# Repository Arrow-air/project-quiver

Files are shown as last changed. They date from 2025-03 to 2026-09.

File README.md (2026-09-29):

# Project Quiver

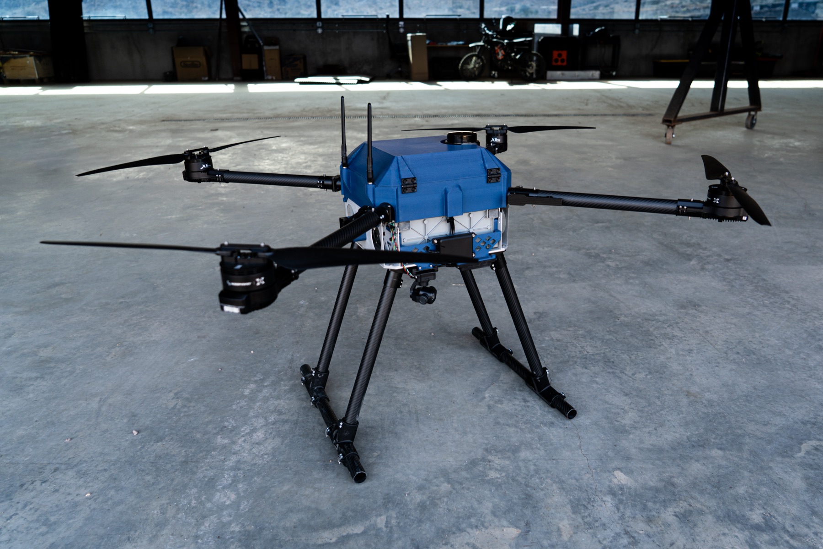
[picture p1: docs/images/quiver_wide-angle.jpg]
Project Quiver PT3


**An open-source, modular quadcopter platform for developers and operators.**

Project Quiver is a 25 kg MTOW drone with 5-8 kg payload capacity, three hot-swappable attachment interfaces, and a distributed electronics architecture. Built for reliability, field serviceability, and customization.

Developed by [Arrow Air](https://arrowair.com) and released under the CERN Open Hardware Licence.

## Key Features

- **Modular payload system** — Three quick-release interfaces (bottom, left, right) for mission equipment
- **Dual GNSS with RTK** — Centimeter-level positioning with backup redundancy
- **Distributed PCB architecture** — Four custom boards that can be individually serviced
- **25-31 min hover endurance** — Tattu 14S 30Ah smart battery with Hobbywing X6 Plus propulsion
- **ArduPilot firmware** — Standard QGroundControl/Mission Planner compatibility
- **Weatherproof design** — Sealed cockpit with rain canopies and drip-proof geometry

## Documentation

📖 **[Full Documentation](https://arrowair.com/quiver/)** — Platform overview, capabilities, and roadmap

The `docs/` folder is hosted on the [Arrow website](https://arrowair.com/quiver/).

| Resource | Description |
|---|---|
| [Assembly Guides](https://arrowair.com/quiver/category/manufacturing/) | Step-by-step build instructions |
| [Engineering Reports](https://arrowair.com/quiver/category/reference--engineering-reports/) | Technical details for each prototype |
| [Meeting Notes](https://github.com/Arrow-air/project-quiver/wiki) | Engineering call notes |

## Repository Structure

```
project-quiver/
├── docs/                    # Documentation (hosted at arrowair.com/quiver)
├── src/
│   ├── quiver/              # CAD assembly — build123d Python package
│   ├── pcb/                 # KiCad PCB designs (4 custom boards)
│   ├── printing/            # 3D print profiles and settings
│   └── manufacturing/       # DXFs and cut sheets for CNC/laser
├── flight-test/             # Historical flight test logs
└── task-grant-bounty/       # Bounty and grant task specifications
```

### CAD Assembly

The CAD source is a [build123d](https://github.com/gumyr/build123d) Python package that composes STEP files into the full drone assembly. This enables programmatic CAD generation and version-controlled mechanical design. See [`src/quiver/`](src/quiver/) for details.

## Getting Started

**Want to build one?** Start with the [Assembly Guides](https://arrowair.com/quiver/category/manufacturing/).

**Want to develop attachments?** Check out:
- [Possible Attachment List](task-grant-bounty/equipment/attachment/0001-possible_attachment_list/information-note.md)
- [Priority Attachment Requirements](task-grant-bounty/equipment/attachment/0002-detailed_attachment_requirement_for_bounty/information-note.md)

**Want a dev-kit?** Dev-kit drones are available for loan to developers with promising projects. Join the [Arrow Discord](https://discord.gg/arrow) to learn more.

## Contributing

We welcome contributions across:
- **Attachments** — Design new payloads for the modular interfaces
- **Electronics** — PCB improvements and new sensor integrations  
- **Mechanical** — Structural design and manufacturing optimization
- **Software** — ArduPilot configs, companion computer features, tooling
- **Documentation** — Guides, tutorials, and translations

See [CONTRIBUTING.md](CONTRIBUTING.md) for guidelines.

## Community

- **Discord** — [discord.gg/arrow](https://discord.gg/arrow)
- **DAO Forum** — [dao.arrowair.com](https://dao.arrowair.com)
- **Flight Tracking** — [project-flight-tracking.vercel.app](https://project-flight-tracking.vercel.app/)

## License

[CERN Open Hardware Licence Version 2 - Strongly Reciprocal (CERN-OHL-S)](LICENSE)

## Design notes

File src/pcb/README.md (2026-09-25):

# PCB Designs

KiCad projects for the Quiver's distributed PCB architecture.

## Board projects

| Directory | BOM | KiCad project | Description |
|---|---|---|---|
| `battery_pcb/` | 3311 | `Front_PCB` (V1.3) | Battery PCB — power switching and protection |
| `main_pcb/` | 3321 | `Quiver_PT3_Main_PCB-rounded` (V1.2) | Main PCB — power and data distribution hub. V1.2 is the board on the Dev-Kit aircraft. |
| `fc_pcb/` | 3331 | `Quiver_PT3_FC_PCB` | Flight Controller PCB — Pix32 V6 adapter board |
| `attach_pcb/` | 3341 | `QuiverAttachPCB` (V1.4) | Attachment Interface PCB (x3) |

Production gerbers live in each project's `production/` folder. Design
history, update notes, and superseded board revisions remain with the
bounty tasks under
[`task-grant-bounty/pt3/electronics/`](../../task-grant-bounty/pt3/electronics/).

## STEP export workflow

Each KiCad project can export a 3D STEP model of the assembled board.
These STEP files go into the CAD assembly tree:

```
pcb/<board>/  ──(KiCad 3D export)──►  ../quiver/equipment/pcb/steps/{BOM}_{name}.step
```

For example, exporting `battery_pcb` produces `3311_battery_pcb.step`, which
should be placed in `../quiver/equipment/pcb/steps/`.

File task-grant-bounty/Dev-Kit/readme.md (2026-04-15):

This folder contains the various information notes prepared for the Dev-Kit build of Project Quiver

- Main PCB Update
- Front PCB Update
- Obstacle Avoidance
- Software in the Loop (SITL) Evaluation
- PCB Vibration Mount
- Comprehensive Main Enclosure Modification
- Sensor Mount Re-modeling
- Structure Weight Reduction
- Improvement of Dust and Water Resistance
- Ethernet Setup Guide

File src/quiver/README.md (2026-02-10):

# Quiver CAD Assembly

Parametric CAD for the Arrow Quiver multi-purpose quadcopter platform,
built with [build123d](https://github.com/gumyr/build123d).

## Folder structure

The project follows the Quiver Bill of Materials (BOM) hierarchy. Top-level
folders map to BOM categories (1000–5000), and subfolders map to subcategories
(XX00). Folder names are descriptive (no numeric prefixes); BOM numbers appear
in STEP file names and module docstrings.

| BOM  | Category / Subcategory | Folder path |
|---|---|---|
| 1000 | Airframe Structure | `airframe_structure/` |
| 1100 | Plates | `airframe_structure/plates/` |
| 1200 | Beams | `airframe_structure/beams/` |
| 1300 | Landing Gear | `airframe_structure/landing_gear/` |
| 1400 | Motor Arm | `airframe_structure/motor_arm/` |
| 2000 | Supporting Structure | `supporting_structure/` |
| 2100 | Attachment Interface | `supporting_structure/attachment_interface/` |
| 2200 | Battery Slider | `supporting_structure/battery_slider/` |
| 2300 | Equipment Mount | `supporting_structure/equipment_mount/` |
| 2400 | Cockpit Enclosure | `supporting_structure/cockpit_enclosure/` |
| 3000 | Equipment | `equipment/` |
| 3100 | Propulsion System | `equipment/propulsion/` |
| 3200 | Peripheral | `equipment/peripheral/` |
| 3300 | PCB | `equipment/pcb/` |
| 3400 | Battery | `equipment/battery/` |
| 4000 | Harness | `harness/` |

Two additional folders live outside the BOM hierarchy:

- **`attachments/designs/`** — Community payload attachment designs
- **`variants/`** — Major structural variant builds

## STEP file naming

STEP files use BOM component numbers as prefixes for traceability:

```
{XXXX}_{descriptive_name}.step
```

Examples:
- `1111_upper_plate.step`
- `1211_cw_long.step`
- `3111_motor.step`

## Custom vs vendor parts

Each subcategory has a `steps/` directory for STEP files:

- **`steps/`** — Custom-designed parts (exported from Fusion 360 or built
  parametrically)
- **`steps/vendor/`** — Supplier-provided STEP models for off-the-shelf
  components (motors, tubes, hinges, etc.)

## Running the assembly

Export the full drone as a STEP file:

```bash
python -m quiver.assembly
```

View in the ocp-vscode 3D viewer:

```bash
python -m quiver.assembly --show
```

Export to a custom path:

```bash
python -m quiver.assembly -o path/to/output.step
```

## Assembly hierarchy

The top-level `assembly.py` composes three BOM categories. Each category
composes its subcategories, and each subcategory loads STEP files from its
`steps/` directory.

```
quiver.assembly
├── airframe_structure.assembly    (1000)
│   ├── plates.assembly            (1100)
│   ├── beams.assembly             (1200)
│   ├── landing_gear.assembly      (1300)
│   └── motor_arm.assembly         (1400)
├── supporting_structure.assembly  (2000)
│   ├── attachment_interface.assembly (2100)
│   ├── battery_slider.assembly    (2200)
│   ├── equipment_mount.assembly   (2300)
│   └── cockpit_enclosure.assembly (2400)
└── equipment.assembly             (3000)
    ├── propulsion.assembly        (3100)
    ├── peripheral.assembly        (3200)
    ├── pcb.assembly               (3300)
    └── battery.assembly           (3400)
```

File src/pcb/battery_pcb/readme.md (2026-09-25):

PCB files are up to date as of 01/05/26 (Front PCB V1.3, the board on the Dev-Kit aircraft). V1.2 gerbers remain in `production/` for reference.

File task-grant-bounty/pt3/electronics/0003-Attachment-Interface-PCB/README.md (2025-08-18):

# Project Quiver Payload Attachment PCB

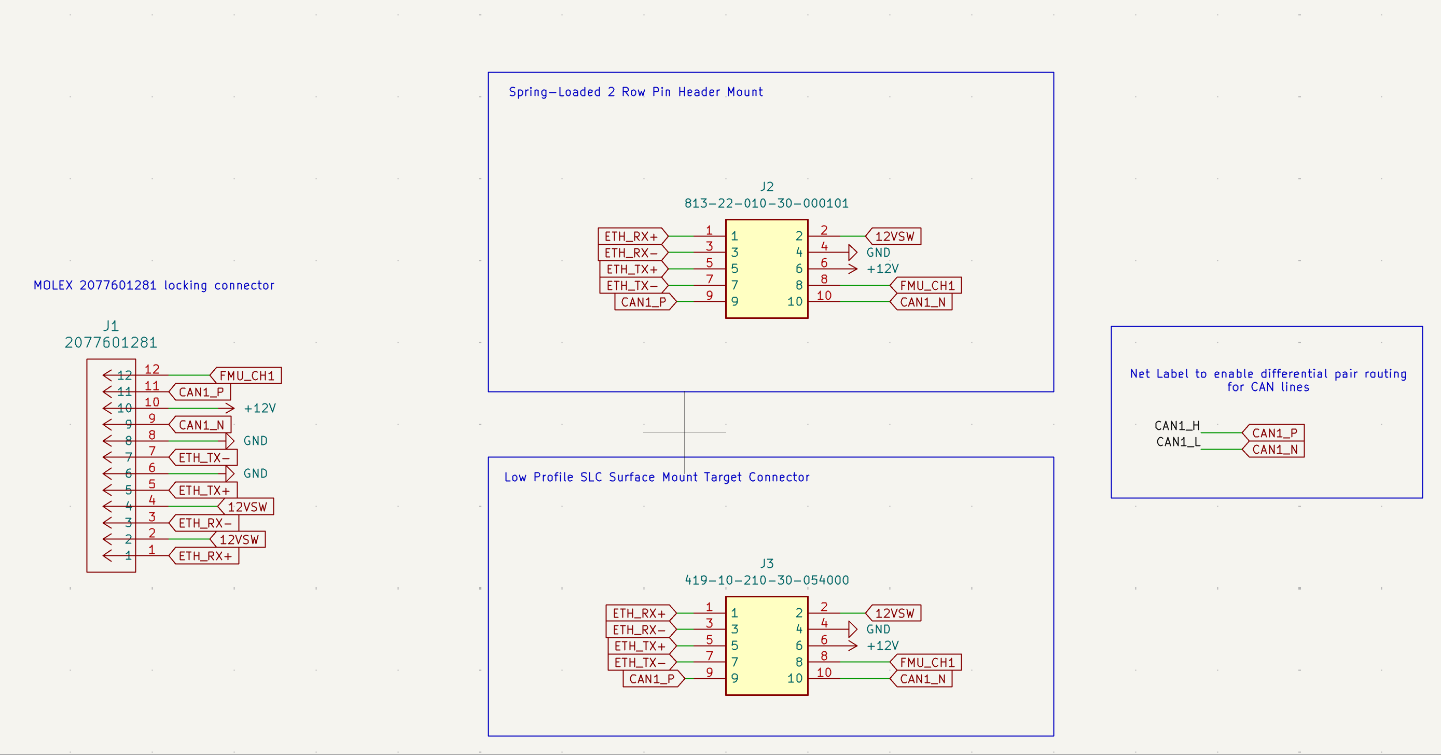
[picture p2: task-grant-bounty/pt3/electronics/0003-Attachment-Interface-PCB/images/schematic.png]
PCB Overview Project Quiver Payload PCB


## Overview

The Project Quiver payload attachment PCB is a simple 2-layer board designed for quickly interfacing payloads with the main system. 
This board provides standardized connectivity and mounting options for various payload configurations.

## Design Features

- **2-layer PCB design** for cost-effective manufacturing
- **Dual 10-pin headers** for flexible connectivity options
- **4x M2 mounting holes** for secure mechanical attachment
- **Configurable gender orientation** - populate either male or female connectors as needed

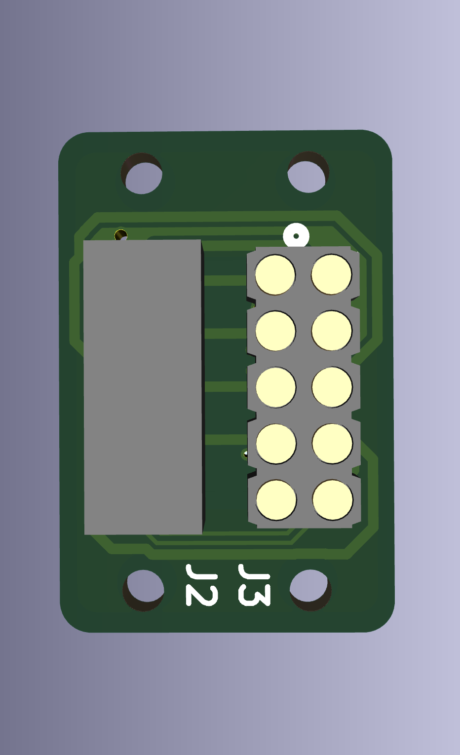
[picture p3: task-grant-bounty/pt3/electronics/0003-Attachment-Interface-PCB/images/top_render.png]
PCB 3D Render Top 3D render showing component placement

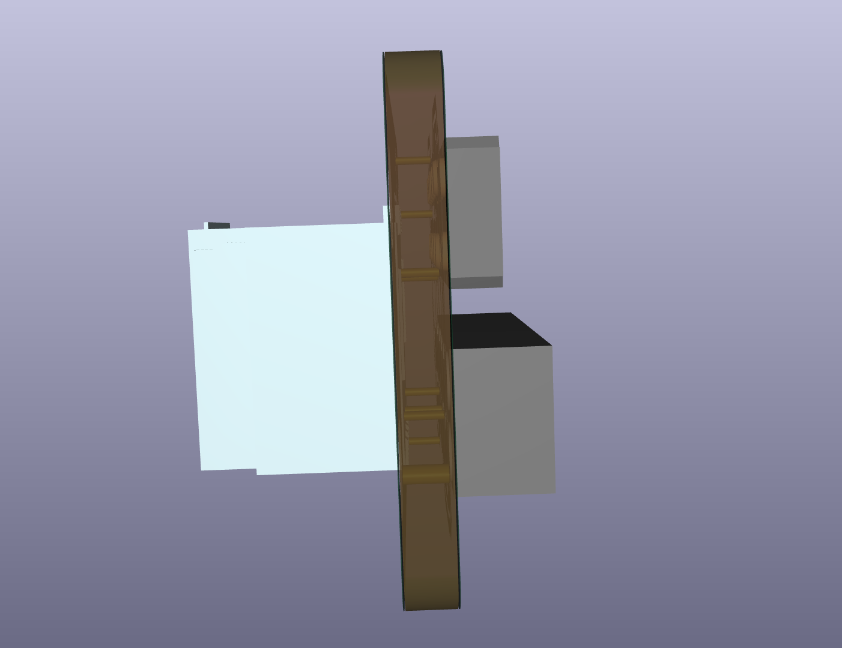
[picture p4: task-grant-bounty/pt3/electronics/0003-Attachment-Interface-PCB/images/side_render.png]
PCB 3D Render Side 3D render showing component placement

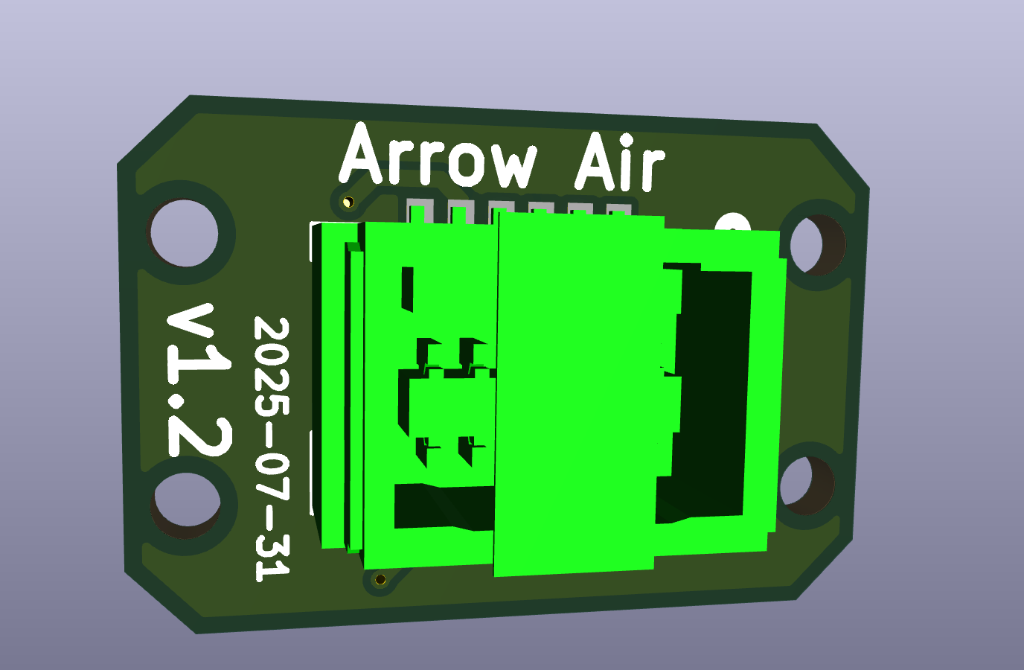
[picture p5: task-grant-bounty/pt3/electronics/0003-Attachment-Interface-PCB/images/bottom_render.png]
PCB 3D Render Bottom 3D render showing component placement


## Hardware Specifications

### Connectors
- **2x 10-pin headers** (2.54mm pitch)
  - Header J3: Female/Flat receiver pin payload interface
  - Header J2: Male/pogo pin interface
  - **Population options:**
    - Install male headers for mating with female cables/boards
    - Install female headers for mating with male cables/boards
    - Populate only one header if single connection is sufficient

### Mechanical
- **Mounting:** 4x M2 threaded holes
- **Board dimensions:** 15.8mm height x 23.5mm width
- **Board thickness:** 1.2mm **(thinner than standard 1,6mm!)**
- **Material:** FR4

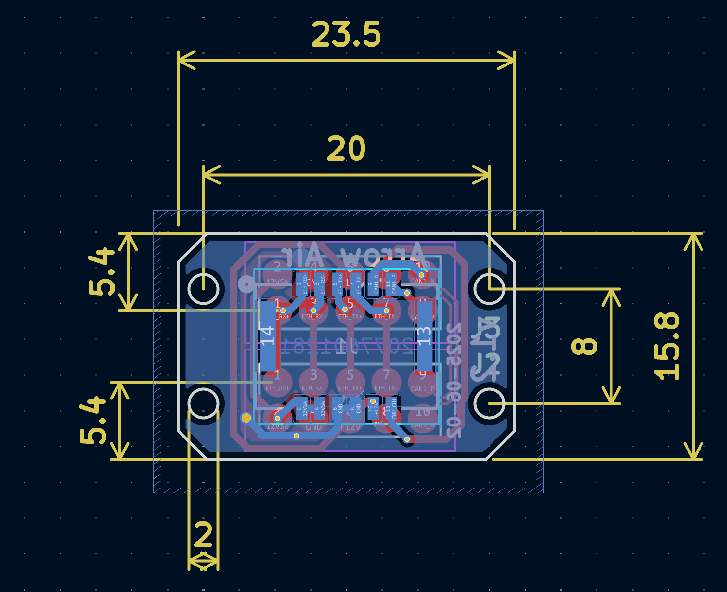
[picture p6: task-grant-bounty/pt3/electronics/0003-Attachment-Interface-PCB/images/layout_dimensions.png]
PCB Dimensions Detailed dimension drawing


## Assembly Instructions

### Component Population

1. **Header Selection:**
   - Determine required mating configuration
   - Install either male or female 10-pin headers (or both if needed)
   - Ensure proper alignment and orientation

2. **Mounting:**
   - Use 4x M2 screws for mechanical attachment
   - Recommended torque: screwdriver tightening, do not use impact driver or drill
   - Ensure even mounting pressure across all four points

### Pinout

**10-Pin Headers (J2 & J3):**

| Pin | J3 Function | J2 Function |
|-----|---|---|
| 1 | ETH_RX+ | ETH_RX+ |
| 2 | 12VSW | 12VSW |
| 3 | ETH_RX- | ETH_RX- |
| 4 | GND | GND |
| 5 | ETH_TX+ | ETH_TX+ |
| 6 | +12V | +12V |
| 7 | ETH_TX- | ETH_TX- |
| 8 | FMU_CH1 | FMU_CH1 |
| 9 | CAN1_P | CAN1_P |
| 10  | CAN1_N | CAN1_N |

**12-Pin MOLEX Locking Connector (J1 - 2077601281):**

| Pin | Function | Description |
|-----|---|---|
| 1 | ETH_RX+ | Ethernet receive positive |
| 2 | 12VSW | Switched 12V power |
| 3 | ETH_RX- | Ethernet receive negative |
| 4 | 12VSW | Switched 12V power |
| 5 | ETH_TX+ | Ethernet transmit positive |
| 6 | GND | Ground reference |
| 7 | ETH_TX- | Ethernet transmit negative |
| 8 | GND | Ground reference |
| 9 | CAN1_N | CAN bus negative |
| 10  | 12V | Main 12V power supply |
| 11  | CAN1_P | CAN bus positive |
| 12  | FMU_CH1 | Flight Management Unit Channel 1 |

**Signal Descriptions:**
- **ETH_RX+/ETH_RX-**: Ethernet receive differential pair
- **ETH_TX+/ETH_TX-**: Ethernet transmit differential pair  
- **12VSW**: Switched 12V power output
- **+12V**: Main 12V power supply
- **GND**: Ground reference
- **FMU_CH1**: Flight Management Unit Channel 1
- **CAN1_P/CAN1_N**: CAN bus differential pair
s for maximum flexibility. J1 provides the same signals with additional ground pins for enhanced signal integrity and current handling.*
*Note: J2 and J3 headers have identical pinout

## Usage

### Configuration Options

1. **Single Header Configuration:**
   - Populate only J1 or J2 as needed
   - Use for simple payload interfaces

2. **Dual Header Configuration:**
   - Populate both headers
   - Enables 2x pin connections for each pinout

### Installation

1. Select appropriate M2 screws for your mounting surface
2. Align PCB with mounting holes
3. Secure with 4x M2 screws
4. Connect payload cables to populated headers

## Design Files

- Schematic: `QuiverAttachPCB.kicad_sch`
- PCB Layout: `QuiverAttachPCB.kicad_pcb`
- Gerber files: `/gerbers/`
- BOM: `QuiverAttachPCB_BOM.csv`

## Revision History

| Version | Date | Changes |
|---|---|---|
| v1.0 | 2025-06-02 | Initial release |
| v1.2 | 2025-07-31 | Center Molex header, adjust edge dimensions |

## Support

For technical questions or issues, please contact kellan@arrowair.com.

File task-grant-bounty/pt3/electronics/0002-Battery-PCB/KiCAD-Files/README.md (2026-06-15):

# KiCad files moved

The KiCad sources for this board now live at
[`src/pcb/battery_pcb/`](../../../../../src/pcb/battery_pcb/) — see that directory for
the current design files. This folder retains the bounty task history.

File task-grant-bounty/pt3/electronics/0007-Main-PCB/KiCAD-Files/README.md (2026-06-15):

# KiCad files moved

The KiCad sources for this board now live at
[`src/pcb/main_pcb/`](../../../../../src/pcb/main_pcb/) — see that directory for
the current design files. This folder retains the bounty task history.

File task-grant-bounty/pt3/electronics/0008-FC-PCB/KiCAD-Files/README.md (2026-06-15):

# KiCad files moved

The KiCad sources for this board now live at
[`src/pcb/fc_pcb/`](../../../../../src/pcb/fc_pcb/) — see that directory for
the current design files. This folder retains the bounty task history.

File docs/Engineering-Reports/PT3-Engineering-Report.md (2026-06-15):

---
title: PT3 Engineering Report
sidebar_position: 3
description: Engineering report for Project Quiver Prototype 3
---

# Project Quiver PT3 Engineering Report

## Executive Summary

Building upon the designs of PT1 and PT2, Quiver PT3 represents a leap forward in design and manufacturing quality.  Significant advancements were made to enhance the reliability, modularity, and operational capabilities based on the lessons learned from building and testing the previous prototypes.  PT3 included a comprehensive redesign to structural components, payload integration, PCBs, navigation accuracy, and sensing technology.  Developments include multiple custom PCBs, redundant GNSS with RTK capabilities, dual radar and LiDAR altimeters, expanded payload interfaces, and various airframe changes that have improved the assembly, maintenance, and expanded the operational capabilities of PT3.  These improvements have resulted in an acceleration towards the goal a multipurpose UAV platform capable of reliable and flexible operations. 

## Introduction

PT3 continues the goal of creating a multi-purpose multi-rotor UAV suited for various operational scenarios with an emphasis on reliability, robustness, and modularity. PT1 showcased basic capabilities and the initial integration relied on a repurposed PCB mixed with various off the shelf components. The structure used a common quadcopter layout with foldable motor beams and propellers. PT 1.5 introduced an updated PCB, solid state relay (SSR), and updated enclosure design for the battery and flight controller. PT2 introduced major overhauls on the structural components, equipment layout, and PCB design. Many of these changes set the platform for PT3 which allowed the design to leverage the extensive testing and feedback from the previous prototypes. The following areas were targeted for improvement in the PT3 design but are not a complete list of updates:

- Waterproof & dustproof cockpit
- Standardized mission attachment connector
- Flight mission planning & automation
- RTK & Precise GNSS
- PCB with kill switch capabilities
- Refined structure for weight reduction

## Evolution of Project Quiver

### Prototype Comparison

| Feature | PT1 | PT2 | PT3 |
| --- | --- | --- | --- |
| Airframe Material | Aluminum/CF/3D prints | Aluminum/CF/3D prints | Aluminum/CF/3D prints |
| Water proof/Dust Proof | No | No | Yes |
| Payload Interfaces | One | One  | Three |
| GNSS System | Basic | Initial RTK | Dual RTK (Holybro DroneCAN H-RTK F9P Rover & Systork Wren Mini), Backup GNSS (Mateksys M9N-G4-3100) |
| Flight Controller | Pixhawk 6X | Mateksys H743 | Pix32 V6 with plans for Pixhawk 6X/Cube Orange |
| PCB Strategy | Repurposed from Feather Testbed | Custom main PCB  | Multiple custom PCBs |
| Battery Management | Contactor controlled by Arduino  | SSR & Pre-charge | Battery PCB with temperature monitoring and kill switch |
| Altimeter Sensors | Radar altimeter | LiDAR | Ainstein US-D1 Radar, Benewake TF03-180 LiDAR |
| Communication  | CAN, Serial, Analog | CAN, Serial, Analog | CAN, Serial, Analog, & Ethernet |
| Raspberry Pi Integration | None | Optional | Optional |
| Testing sites | US | Germany | US & Germany  |

## Airframe CAD Architecture

The PT3 airframe CAD model introduces weight optimizations, multiple features for ease of maintenance, and additional quick-release attachment interfaces compared to earlier prototypes. The design was developed in Fusion 360 and informed by mechanical reasoning, lessons learned from past prototype failures, and FEA insights.

A detailed part list and link to the .step file can be found in the information note included in the report appendix. 

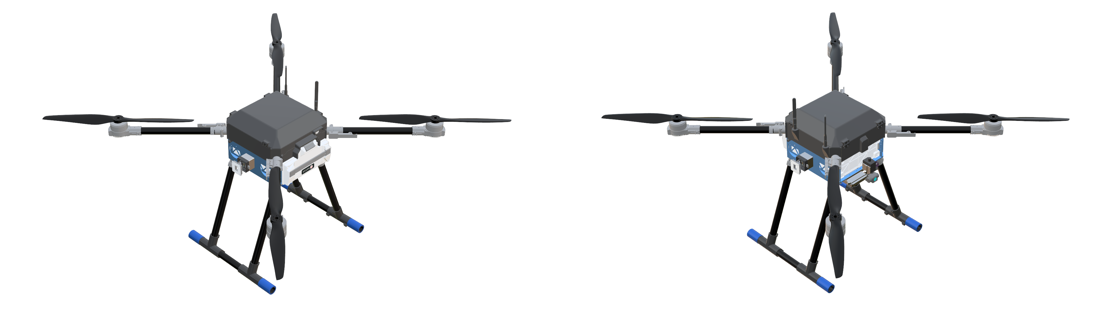
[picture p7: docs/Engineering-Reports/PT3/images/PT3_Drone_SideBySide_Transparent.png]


## Detailed Technical Improvements (PT3)

This portion of the report will highlight and summarize the modifications to PT3. For additional details please refer to the appendix of the report. 

### Airframe & Structural Improvements

The PT3 structural design is an evolution of the PT2 airframe, preserving core geometries while incorporating modifications to resolve limitations observed during PT2 operations. These enhancements address environmental sealing, increased payload mounting provisions, structural mass optimization, additional cable routing provisions, and mitigations for electromagnetic interference.  The following sections will cover the various airframe modifications targeted for PT3.

**Enclosure Assembly** 

Total|Explode 
:-:|:-:
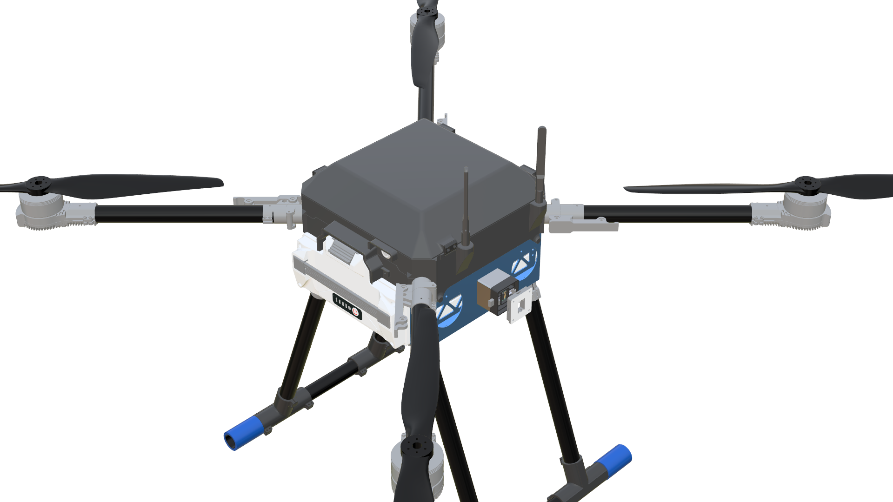
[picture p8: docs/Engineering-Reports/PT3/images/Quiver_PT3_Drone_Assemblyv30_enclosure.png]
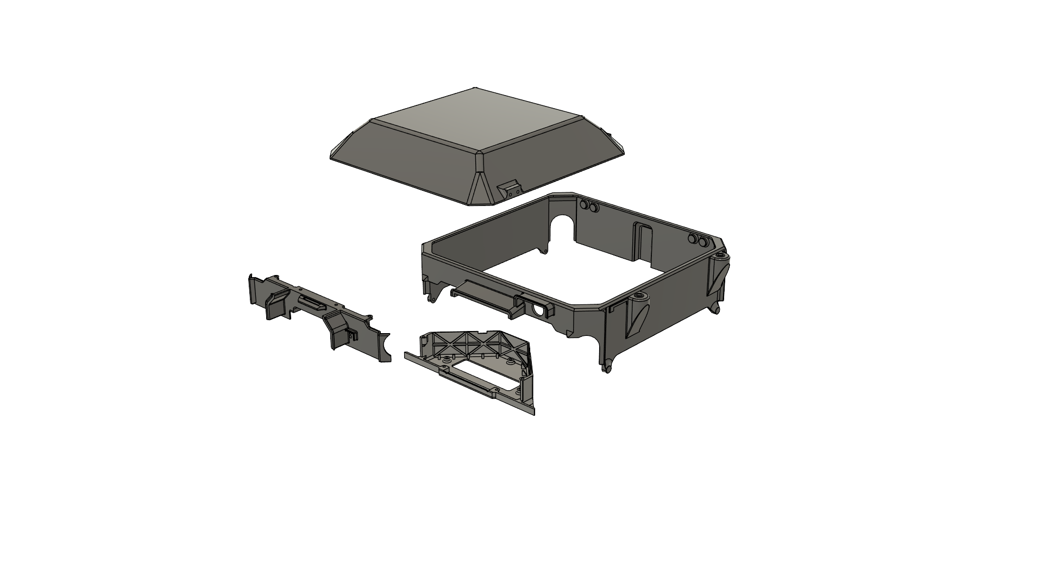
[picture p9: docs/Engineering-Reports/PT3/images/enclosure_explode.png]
 | 

A comprehensive redesign of the battery and avionics enclosures in PT3 added weather resistance, improved heat management, and enhanced PCB structural support without sacrificing the maintainability achieved in PT2. The enclosure assemblies are divided into four primary components: the Battery PCB enclosure, the Main enclosure, the Front lid, and the Top cap.

Multiple design techniques were applied to protect the electronics weatherproof from rain and dust. Openings to the electrical compartments feature integrated rain canopies and drip-proof structures, while enclosure gaps and edges use reverse slope geometries to further improve water resistance. A dedicated enclosure was developed for the Battery PCB, incorporating a heat sink that interfaces with the aluminum airframe for heat dissipation. Additionally, mechanical reinforcements were added for the PCB while minimizing the mass of non load bearing sections.

The main enclosure includes a reserved RP-SMA mounting bracket for the telemetry antenna, ensuring robust mechanical support and straightforward integration. The top cap retains the hinged operation of PT2 but has been completely reshaped and resized to provide the clearance required for the RTK-GNSS receiver located in the cockpit.

**GNSS Stand**

The GNSS receiver is mounted 2 cm above the FCU enclosure to reduce EMI, supported by a custom arch bracket that provides stability without contacting the FC or its PCB.

**Attachment Interface** 

PT3 retains the quick release mechanism from previous prototypes while expanding capacity to support three payloads. Each interface is mounted on a modified plate with dedicated screw and cable openings, and fitted with a 3 cm extension adapter to improve clearance from the aircraft body and ease maintenance. Side facing cable ports prevent abrasion and water ingress, enhancing durability in operational environments.

**Battery Wall Modifications**

The PT3 battery walls retain PT2’s core geometry, with modifications improving attachment integration, cable management, and maintenance access.  M3 screw holes were added on each side to accommodate the payload clearance adapters. Larger clearance holes were incorporated to allow a screwdriver to pass through for direct access to the fasteners, simplifying installation and removal without disassembling surrounding components. Chamfered access holes and extended cutouts simplify motor arm connector screw replacement, and additional harness cutouts on the top and bottom surfaces enable cleaner routing of cables between layers.

**Battery Slider Modification**

The battery slider was updated to align with the larger clearances on the PT3 battery walls. Recesses were added in line with the side attachment interface mounting holes to provide screwdriver access.

**Harness Cutouts on the Plates**

Routing provisions added to route cables between layers. 

**Main PCB Mount**

Main PCB holder was modified so that the holes are aligned with PCB installation holes. Additional anchors were created for the flight controller and Raspberry Pi.

**Cockpit Support Beams**

Cutouts on the cockpit support beams are created for weight reduction of 200 g.

### Electronics Integration

PT3 moves away from the single, centralized PCB approach of PT2 in favor of a distributed architecture built around four custom boards: the Battery PCB, Main PCB, Flight Controller (FC) PCB, and Attachment Interface PCB. This modular layout allows each board to be optimized for its specific role, reducing interdependencies and simplifying maintenance. PT3 improves redundancy in critical systems and creates flexibility for integrating different payloads, sensors, and other equipment. The design also enhances troubleshooting and upgrade workflows, as individual PCBs can be serviced or replaced without disturbing unrelated subsystems. To further aid diagnostics and field servicing, various probe points and status LEDs have been incorporated, providing users with accessible test locations and clear visual indicators of system status.

A brief summary is provided below of the PCBs and their functionality. Detailed description of their operation, components, and manufacturing can be found in their respective information notes, which are included in the appendix of this report.

### Battery PCB

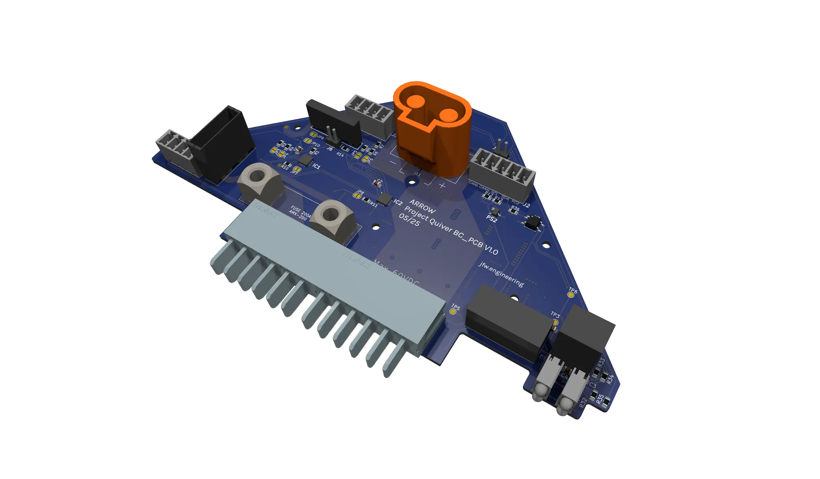
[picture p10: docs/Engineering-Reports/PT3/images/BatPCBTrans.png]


The newly designed Battery PCB is responsible for managing, protecting, and monitoring the primary power flow from the Tattu Smart Battery to the Main PCB. It integrates power switching, pre-charge control with a bypass, and telemetry functions into a single board, using a combination of MOSFETs, SSRs, voltage regulators, fuses, TVS diodes, temperature sensors, and indicator LEDs.

Key functions include safe ESC pre-charge, over current protection via high capacity fuses, and telemetry. Battery status is transmitted over CAN, while temperature data is sent over I²C. Status LEDs and dedicated probe points are positioned to give clear visual indicators and accessible test locations for diagnostics in the field.

The PCB design supports both pre-charge and full-power states. Custom high current Molex connectors handle the main power path, while Eurostyle connectors provide interface points for the flight controller and auxiliary systems. The board’s 4-layer FR-4 construction, ENIG finish, and robust copper weight ensure durability under high load conditions. The design also incorporates mechanical reinforcement and a heat-sinking interface to the airframe for thermal management. Multiple test points allow quick verification of voltages, gate signals, and system readiness.

By combining critical protection, switching, and monitoring functions into a dedicated module, the Battery PCB reduces wiring complexity, improves maintainability, and enhances operational reliability in PT3.

[KiCAD Files](https://github.com/Arrow-air/project-quiver/tree/main/src/pcb/battery_pcb)

### Main PCB

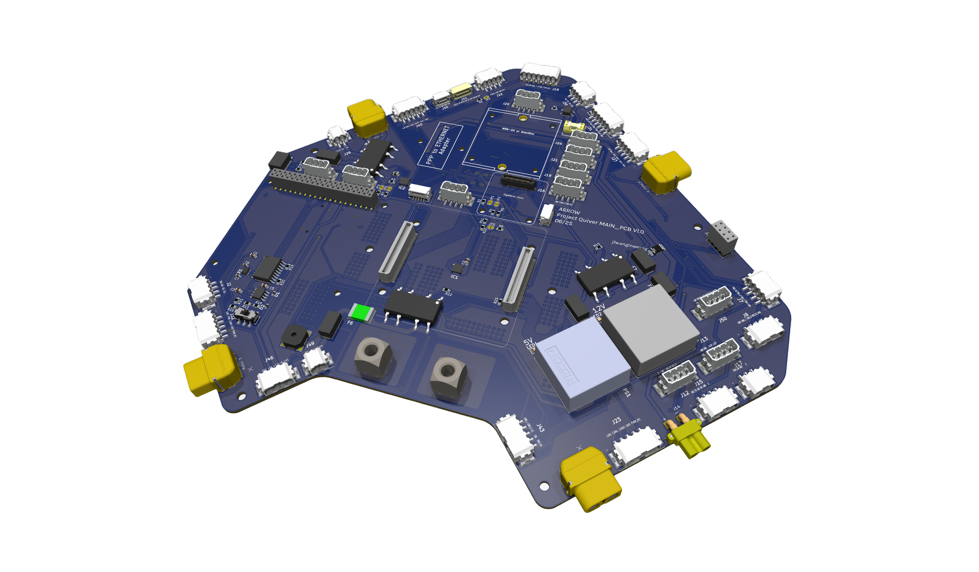
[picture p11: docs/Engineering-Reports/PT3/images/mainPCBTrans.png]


The PT3 Main PCB serves as the primary hub for distributing power, data, and control signals between the flight controller and the aircraft’s major subsystems. Its design is heavily based on the PT2 Main PCB, retaining the overall functional block layout and many proven interconnection schemes, but with a number of targeted upgrades to improve flexibility, serviceability, and system integration.

One of the many significant changes from PT2 is the replacement of Euro style terminal blocks with Phoenix connectors, enabling faster prototyping and more reliable field connections. The PT3 board also introduces an additional high voltage output port rated for 60 V or less, three dedicated payload connectors for the bottom and both side attachment interfaces, and provisions for a secondary backup GNSS receiver. Ethernet, CAN, and UART routing have been expanded to accommodate a wider range of payloads and sensors, including the Ainstein US-D1 radar altimeter and Benewake TF03 LiDAR.

The Main PCB also incorporates dedicated stacking connectors that allow the Flight Controller PCB to mount directly on top, forming a compact and serviceable electronics stack. Like the other PT3 PCBs, it integrates probe points and LED indicators throughout the board to provide clear visual feedback and accessible test locations for power rails, control signals, and subsystem health.

In addition to payload integration improvements, the board maintains robust power management features from PT2, including dedicated 5 V and 12 V DC-DC converters, SSR controlled payload power switching, and pre-charge bypass control. Expanded CAN and Ethernet interfaces allow for more complex networked subsystems, while the improved interconnect layout enhances both assembly efficiency and in-field maintainability.

The Main PCB functions as a central hub, managing power and communication between subsystems, including Ethernet and advanced CAN networks. The Flight Controller PCB accommodates the Pix32 V6 and includes advanced EMI filtering and power protection features, as discussed during the selection phase.

[KiCAD Files](https://github.com/Arrow-air/project-quiver/tree/main/src/pcb/main_pcb)

### FC PCB

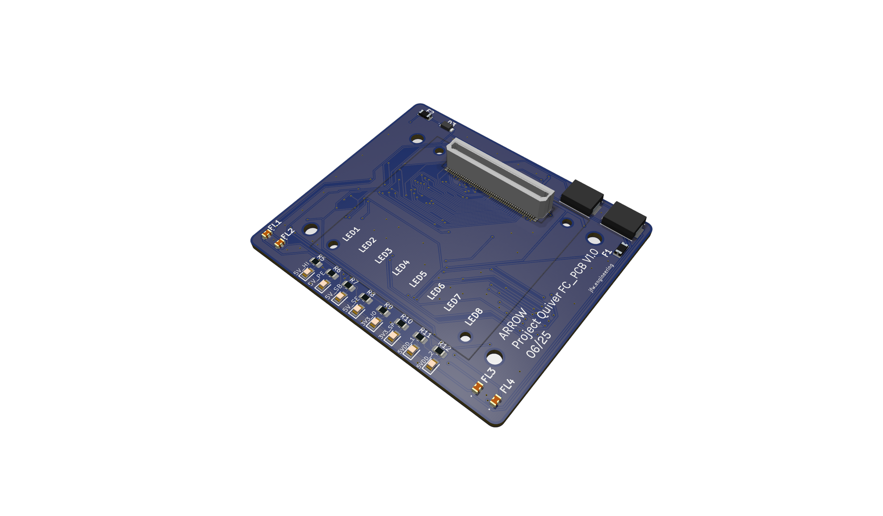
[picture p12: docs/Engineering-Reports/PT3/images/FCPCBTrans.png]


The FC PCB is an adapter board for the Pix32 V6 flight controller. It includes breakouts for the various PWM, GPIO, GPS, I²C, CAN, S.BUS, and power pins on the flight controller. Various components were included based on the documentation provided by Holybro for the Pix32 V6 Schematic. Diagnostic LEDs indicate FC power state and sensor activity, while probe points facilitate troubleshooting without interrupting harness connections.

[KiCAD Files](https://github.com/Arrow-air/project-quiver/tree/main/src/pcb/fc_pcb)

### Attachment Interface PCB

Provides the electrical interface for modular payloads through the aircraft’s quick-release attachment system. It routes regulated power and data lines from the Main PCB to the payload and supports multiple communication standards to accommodate different equipment types. The design allows hot-swapping of payloads without disturbing the main PCB.

### Flight Controller Selection & Integration

| Flight Controller | Key Features | Pros | Cons |
| --- | --- | --- | --- |
| Pixhawk 6X / 6X Pro | Expanded IO, Pro has better sensors & loop performance | Robust, extensible, familiar system | Higher cost, Pro version significantly more expensive |
| CubePilot+ | Redundant FCs and more IMUs | Feature-rich, aerospace-grade | ~$200 more expensive than 6X Pro |
| uAvionix George | Manned aircraft-grade with FAA cert-ready architecture | Extensive integration potential | Overkill for current unmanned use |
| Auterion Skynode | Full-stack system with CC and LTE | Plug-and-play, high-end | Overkill for current needs, less transparency |
| Mateksys H743-SLIM V3 | Minimalistic, low-cost, ArduPilot compatible | Extremely cheap, small form factor | Manual wiring required, reliability concerns |
| Pix32 V6 | Modular design, no onboard Ethernet | Affordable, flexible PCB integration | Requires adapter for Ethernet, breakout board needed |

The flight controller for PT3 was selected after an evaluation of available autopilot boards.  Candidates included the Pixhawk 6 X, 6 X Pro, Cube Pilot Plus, H743‑Slim V3, uAvionix George and Auterion Skynode.  After weighing cost, sensor quality, interface support and redundancy, the **Pix32 V6** was selected as the baseline FC for PT3.  This choice balances performance and affordability for prototyping while providing a clear upgrade path to a Pixhawk 6 X or Cube Orange in later iterations. The Pix32 V6 offers a well documented software stack and various form factors that integrate easily with the Main PCB. 

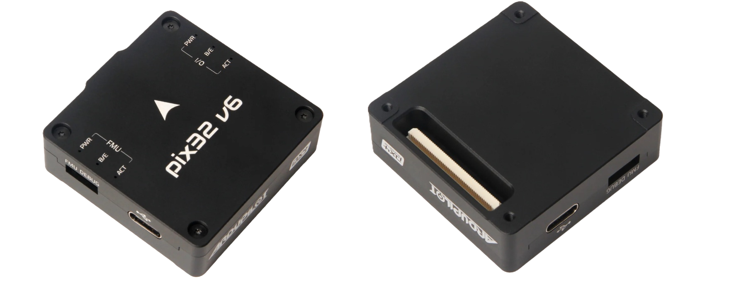
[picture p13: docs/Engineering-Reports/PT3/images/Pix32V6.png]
FC Module


### Navigation and Altimetry Systems

PT3 introduces a redundant navigation system composed of dual real time kinematic (RTK) GNSS modules and complementary altitude sensors. The primary GNSS solution uses either the **Holybro DroneCAN H‑RTK F9P Rover** or the **Systork Wren Mini.** Both are built around the u‑blox F9P receiver and communicate over DroneCAN. To ensure redundancy, a **Mateksys M9N‑G4‑3100** provides an affordable backup. The primary GNSS unit is mounted on a custom 3D printed arch bracket that raises it by 2 cm above the flight controller, reducing electromagnetic interference and giving a clean line of sight to satellites. The Mateksys module has a dedicated mounting location on the Main PCB. The autopilot blends data from these GNSS sources and promotes the backup if the primary fails.

Altitude measurement in PT3 combines the strengths of radar and LiDAR. Where PT1 used an **Ainstein US‑D1 radar altimeter** and PT2 relied on a **Benewake TF03‑180 LiDAR**, PT3 accommodates both to ensure accurate altitude sensing across varied terrain. The US‑D1 provides reliable readings from 5 m up to 400 m using a 24 GHz radar that is unaffected by fog, dust or rain. The TF03‑180 LiDAR delivers high‑resolution measurements from 0.1 m to 180 m for precise low‑altitude hovering and terrain following. Both sensors are mounted on a dedicated bracket on one front of the airframe. The custom designed bracket spaces them to prevent interference and angles them downward to measure ground clearance directly beneath the aircraft. The sensors connect to the flight controller via CAN and their outputs are fused by the autopilot to maintain accurate altitude control across a wide range of operating conditions.

### Raspberry Pi and Communication Systems

A Raspberry Pi companion computer is integrated into PT3 to handle tasks that exceed the Pix32 V6’s onboard processing, such as computer vision, advanced autonomy algorithms and high rate data logging. The Pi connects to the Main PCB via Ethernet and a regulated power line, and communicates with the flight controller over MAVLink. It also interfaces directly with payload sensors and cameras, allowing real time image processing and mission planning. Flight critical functions remain on the Pix32 V6, while the Pi executes non critical scripts and other workloads.

**PT3’s communication systems** integrates multiple physical links for operational resilience. A SIYI telemetry air unit, similar to the one fielded on PT1, streams HD video and telemetry to the ground station over MAVLink. Internally, a combination of CAN and Ethernet networks link the Main PCB, Flight Controller PCB, altimeters, GNSS modules, and payload ports, ensuring reliable data exchange across subsystems.

Although not included in the baseline configuration, the Main PCB incorporates a reserved interface for a Mateksys telemetry unit, allowing rapid integration of an additional radio if operational requirements change. By combining multiple systems with hard-wired digital buses, PT3 maintains robust communications across diverse mission profiles and environmental conditions.

## Performance Metrics & Comparative Analysis

PT3 performance evaluation follows a standardized methodology for comparing prototypes across control behavior, stability, efficiency, and navigation accuracy. Metrics are extracted from ArduPilot flight logs using Mission Planner, MAVExplorer, and custom scripts. Tests cover rate tracking error, vibration analysis, power efficiency, climb performance, yaw authority, waypoint tracking, and glide capability. Results are collected under consistent environmental and configuration conditions to ensure fair comparisons. The full methodology, including calculation formulas and evaluation criteria, is provided in the appendix.

## Conclusions & Future Recommendations

PT3 represents a substantial advancement in the Project Quiver series. It introduces a distributed electronics architecture with four custom PCBs, dual GNSS and dual altitude sensors, three modular payload interfaces, and a refined airframe that balances weight reduction with improved durability. These upgrades yield better navigation accuracy, smoother flight, shorter maintenance times and greater mission versatility than previous prototypes. The modular design also facilitates rapid prototyping of new payloads and subsystem upgrades.

Future work should focus on further increasing computing power by migrating to a Pixhawk 6 X or Cube Orange flight controller, developing a standard gimbal for imaging payloads, and expanding the test campaign to include complex mission profiles. Performing finite element analysis and destructive testing on 3D printed structures will validate the weight reduction strategy. Additional automation of mission planning using the Raspberry Pi’s computer vision capabilities and integration of obstacle‑avoidance sensors will enhance autonomy. Refinement of manufacturing processes and documentation will streamline assembly for production scale builds.

## Appendices (Detailed references)

### Electronics
- [Battery PCB Information Note](https://github.com/Arrow-air/project-quiver/blob/main/task-grant-bounty/pt3/electronics/0002-Battery-PCB/information-note.md)
- [Attachment Interface PCB Information Note](https://github.com/Arrow-air/project-quiver/tree/main/task-grant-bounty/pt3/electronics/0003-Attachment-Interface-PCB)
- [Rangefinder Information Note](https://github.com/Arrow-air/project-quiver/blob/main/task-grant-bounty/pt3/electronics/0005-Rangefinder/information-note.md)
- [GNSS Information Note](https://github.com/Arrow-air/project-quiver/blob/main/task-grant-bounty/pt3/electronics/0006-GNSS/information-note.md)
- [Main PCB Information Note](https://github.com/Arrow-air/project-quiver/blob/main/task-grant-bounty/pt3/electronics/0007-Main-PCB/information_note.md)
- [FC Information Note](https://github.com/Arrow-air/project-quiver/blob/main/task-grant-bounty/pt3/electronics/0008-FC-PCB/information_note.md)

### Flight Controller
- [FC Roadmap Information Note](https://github.com/Arrow-air/project-quiver/blob/main/task-grant-bounty/pt3/flight-controller/0001-fc-roadmap/information-note.md)
- [FC Setup Guide](https://github.com/Arrow-air/project-quiver/blob/main/task-grant-bounty/pt3/flight-controller/0002-flight-controller-setup/information-note.md)

### Airframe
- [PT3 Airframe Modifications Information Note](https://github.com/Arrow-air/project-quiver/blob/main/task-grant-bounty/pt3/structural/0001-comprehensive_airframe_modification/information-note.md)
- [Airframe CAD Architecture Information Note](https://github.com/Arrow-air/project-quiver/blob/main/task-grant-bounty/pt3/structural/0002-Airframe-CAD-Architecture.md)

### Assembly Guides
- [All](https://github.com/Arrow-air/project-quiver/tree/main/docs/Archive/PT3-Assembly-Guides)

### Misc
- [Performance Metrics Information Note](https://github.com/Arrow-air/project-quiver/blob/main/task-grant-bounty/Tools/Performance-Metrics/information-note.md)

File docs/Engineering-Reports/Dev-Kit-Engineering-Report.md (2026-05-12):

---
title: Dev-Kit Engineering Report
sidebar_position: 4
description: Engineering report for Project Quiver Dev-Kit
---

# Project Quiver Dev Kit Engineering Report

## Executive Summary

The Quiver Dev-Kit is the first commercial release of Project Quiver, an open source heavy lift quadcopter platform developed by Arrow Air. This report documents the technical work carried out from September 2025 through early 2026 to bring the PT3 prototype to a stable developer release. It is a delta document. The structural modifications, electronics revisions, software development, and obstacle avoidance integration covered here represent changes from PT3. A Platform Engineering Report providing a complete reference for the Quiver platform as a whole is planned as a separate document.

The structural modifications centered on weight reduction and weatherproofing. Plate thinning succeeded on the upper airframe but failed under payload on the lower frame, an outcome that FEA did not predict and that a 7 kg payload flight test was required to surface. The final configuration retains thinned upper plates and keeps the lower frame and battery bay walls at original thickness. Weatherproofing was validated to IP53 through garden hose testing and confirmed suitable for light rain operations.

Electronics revisions focused on reliability and tighter integration of the companion computer and networking hardware. The four-PCB architecture received improved power protection, a dedicated backup supply for the flight controller, and a vibration isolation mount that decouples the PCB stack from propulsion vibration. Copper bus bars replaced cabling on the battery board for high current capacity, and surface mounted standoffs now secure the Raspberry Pi and Ethernet switches directly to the Main PCB. For convenience, various connectors were updated on the PCBs to match the default on the system peripherals. 

Obstacle avoidance integration combined an RPLidar S2L and NanoRadar MR82 with a custom ArduPilot firmware build running the BendyRuler algorithm. Software in the loop (SITL) simulation established safe operating parameters ahead of field testing, which is structured across four phases and has not yet begun. An intermittent LiDAR dropout under flight conditions is under active investigation.

The software work produced two things: Quiver Hub, a web application with five core operator applications and an extensibility framework for custom payload integrations, and the Quiver SDK, which runs two persistent services on the Raspberry Pi for telemetry relay and job execution. As a first integration, point cloud data from an RPLidar payload was streamed through the companion computer to Quiver Hub and rendered in the browser in real time, confirming the data path from onboard sensor to operator display works as intended.

With Remote ID integration validated in April 2026 via DroneCAN, endurance flight testing is the remaining prerequisite before first external shipments. Per-operator configuration of the UAS ID and operator credentials is required before each unit ships. EASA C3 certification was deferred based on cost relative to the current development stage.

---

## Evolution of Project Quiver

### Prototype Comparison

| Feature | PT1 | PT2 | PT3 | Dev-Kit |
| --- | --- | --- | --- | --- |
| **Airframe Material** | Aluminum/CF/3D prints | Aluminum/CF/3D prints | Aluminum/CF/3D prints | Aluminum/CF/3D prints (upper plates thinned to 1 mm) |
| **Weatherproofing** | No | No | Partial (untested) | IP53 validated |
| **Enclosure** | Standard | Standard | Standard | Modified: LiDAR mount, steel latches, module plate |
| **Landing Gear** | Fixed | Fixed | Detachable (prototype) | Detachable 30 mm (production, RJX Hobby) |
| **Payload Interfaces** | One | One | Three (C1/C2/C3) | Three (C1/C2/C3) |
| **GNSS System** | Basic | Initial RTK | Holybro F9P Rover Mini & Mateksys M9N-G4-3100  | Holybro F9P Rover Mini & Mateksys M9N-G4-3100 |
| **Flight Controller** | Pixhawk 6X | Mateksys H743 | Pix32 V6 | Pix32 V6 |
| **PCB Strategy** | Repurposed from Feather Testbed | Custom main PCB | Multiple custom PCBs (first revision) | Revised PCBs: JST-GH connectors, 5V backup, vibration mount |
| **Battery Management** | Contactor controlled by Arduino | SSR & Pre-charge | Battery PCB w/ temp monitoring and kill switch | Battery PCB: upgraded MOSFETs, copper bus bars |
| **PCB Vibration Isolation**  | None | None | None | Rubber dampener mount (3D printed adapter plate) |
| **Altimeter Sensors** | Radar altimeter | LiDAR | Ainstein US-D1 Radar, Benewake TF03-180 LiDAR  | Same sensors, redesigned X-pattern mount |
| **Communication** | CAN, Serial, Analog | CAN, Serial, Analog | CAN, Serial, Analog, Ethernet | CAN, Serial, Analog, Ethernet |
| **Raspberry Pi Integration** | None | Optional | Optional | Integrated on Main PCB (SMD standoffs) |
| **Obstacle Avoidance** | None | None | Sensors selected | RPLidar S2L + NanoRadar MR82, BendyRuler |
| **Software Platform** | None | None | None | Quiver SDK + Quiver Hub |
| **Remote ID** | None | None | None | DroneCAN integration validated; per-operator configuration required |
| **Transport Case** | None | None | None | Pelican 1640 w/ custom laser cut foam |
| **Testing Sites** | US | Germany | US & Germany | US & Germany |

---

## Technical Improvements

This portion of the report highlights and summarizes the modifications introduced for the Dev-Kit. For additional details, refer to the individual information notes linked in the Appendix.

### <ins>Airframe & Structural Improvements</ins>

The Dev-Kit structural design is an evolution of the PT3 airframe, preserving core geometries while incorporating modifications to resolve limitations observed during PT3 operations. These enhancements address environmental sealing, increased payload mounting provisions, structural mass optimization, and additional cable routing provisions.

#### Weatherproofing

The Dev-Kit was designed and validated to IP53, covering protection from dust sufficient to interfere with operation and from water sprayed at any angle. Validation was performed by spraying the sealed enclosure with a garden hose across multiple angles, with Julius conducting the primary water testing in February 2026. Seven primary ingress points were identified and addressed:

| Area | Solution |
| :--- | :--- |
| Lid to enclosure gap | Silicone sealing strip (groove and lip design) |
| ESC cable holes | Rubber grommets |
| Battery wall rectangular holes | Oval rubber seal, cut to pass cables |
| Plate to enclosure gap | No action required. Silicone can be applied if needed. |
| Front side cable entrance | Entrance removed from the enclosure |
| Battery PCB compartment gap | Removable silicone sealant (e.g., Würth 08933311) |
| LiDAR cable entrance hole | Adhesive silicone sealant (e.g., Würth 08901003) |

For the lid seal specifically, two validated solutions were developed in parallel:

- **Liquid silicone gasket (Version 1):** A groove on the lid is filled to half depth with 30A hardness liquid silicone. Once cured, it forms a custom fitted waterproof gasket.
- **Foam strip seal (Version 2):** An 8 mm diameter silicone foam strip (Uxcell) is inserted into a groove on the main enclosure body to act as a compression seal.

Julius's foam strip seal was adopted as the primary design following water testing in February 2026.

> [!NOTE]
> A short flight in light rain is feasible with these sealing changes applied. The battery connector remains a known ingress risk at the IP53 boundary.

| Lid seal — foam strip | ESC cable grommets | Battery wall seal | Battery PCB gap |
| :---: | :---: | :---: | :---: |
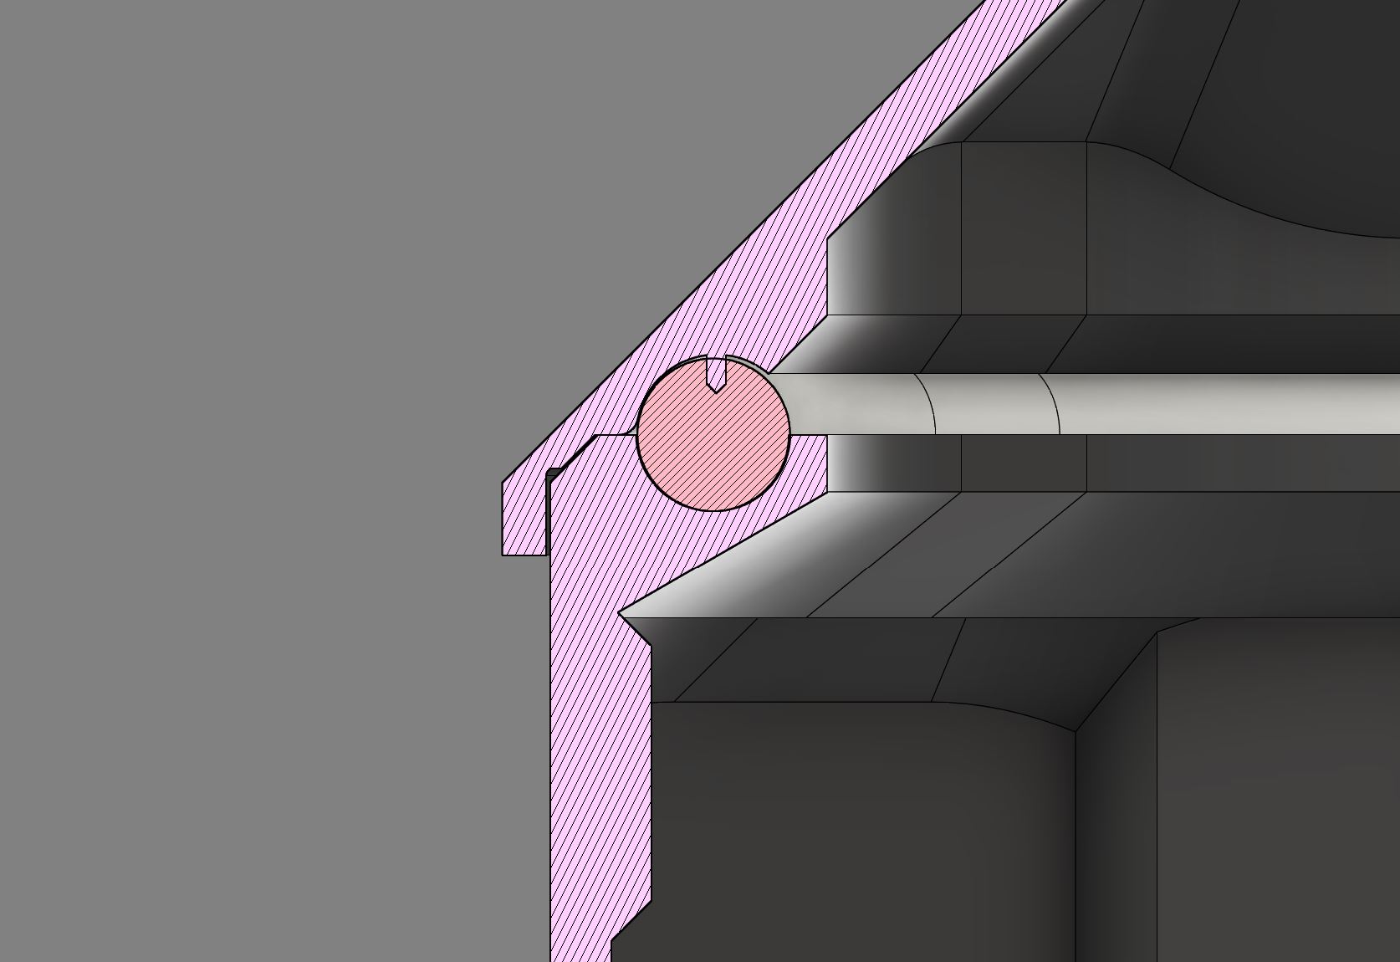
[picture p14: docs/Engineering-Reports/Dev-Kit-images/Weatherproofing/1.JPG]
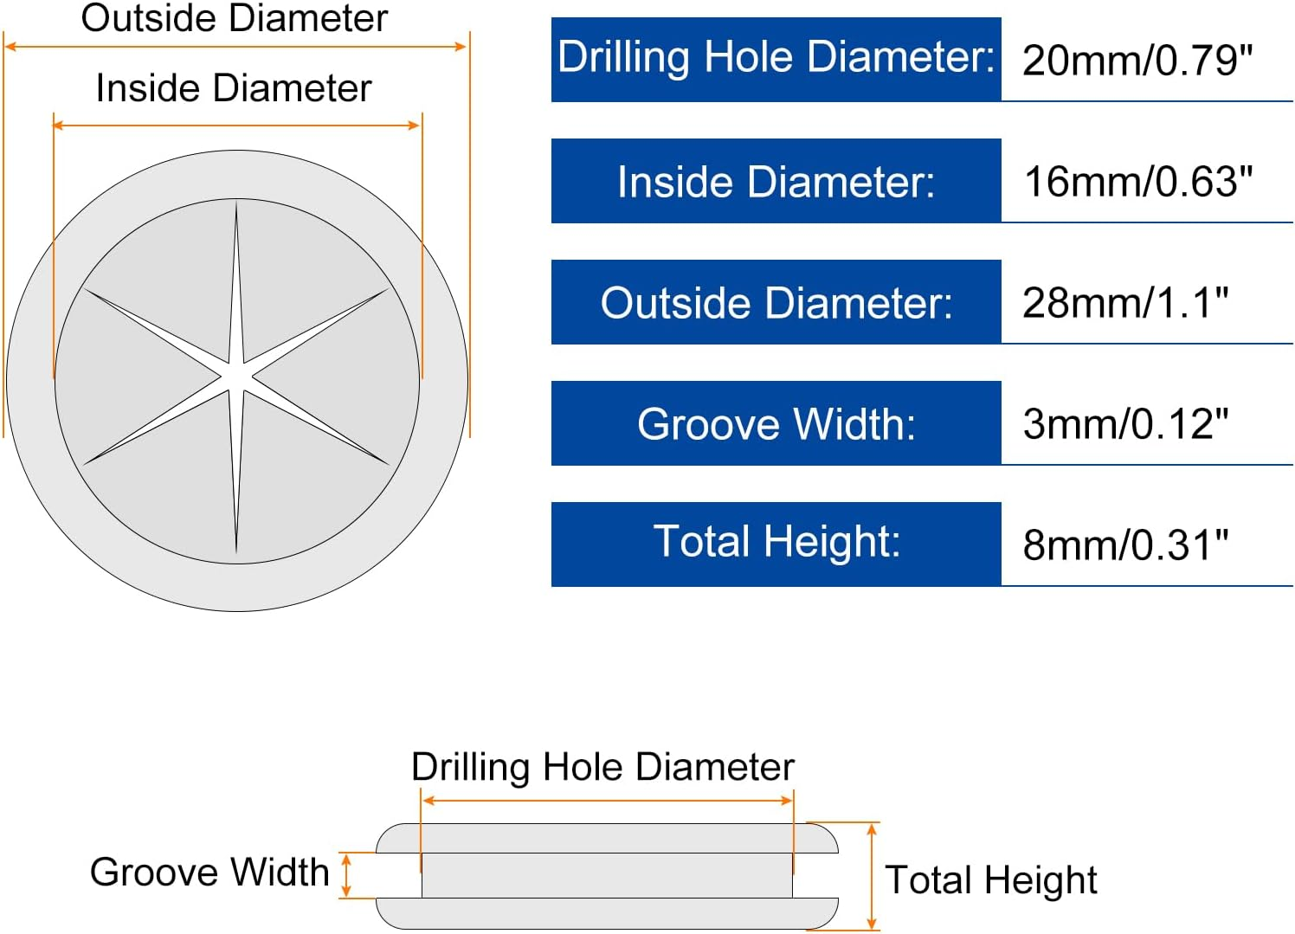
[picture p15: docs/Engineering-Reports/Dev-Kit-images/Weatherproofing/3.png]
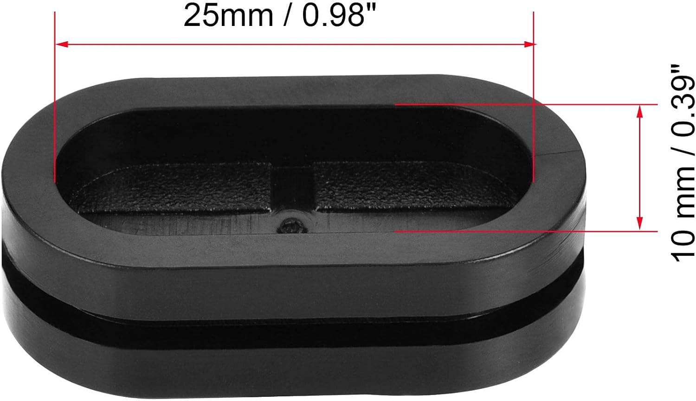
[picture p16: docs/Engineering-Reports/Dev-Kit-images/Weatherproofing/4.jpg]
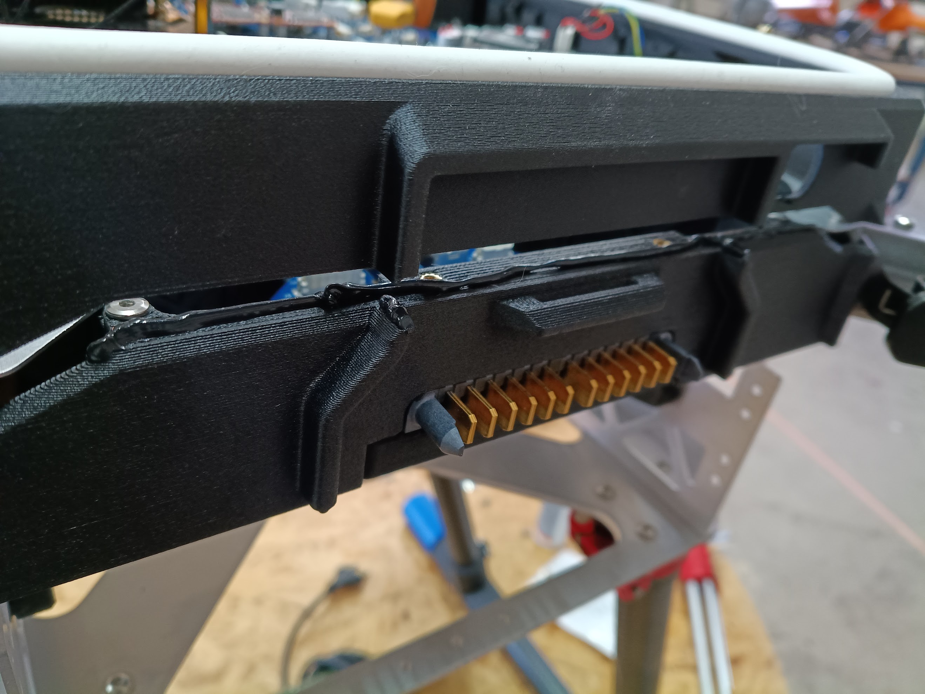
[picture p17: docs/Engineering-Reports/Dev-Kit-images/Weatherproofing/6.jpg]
|  |  |  |  |

#### Main Enclosure Modifications

The main enclosure and cockpit lid were comprehensively redesigned to support the Dev-Kit's expanded sensor suite, improved serviceability, and weatherproofing requirements. Two design versions were developed (Version 1 and Version 2) and are available for 3D printing.

| Version 1 | Version 2 |
| :---: | :---: |
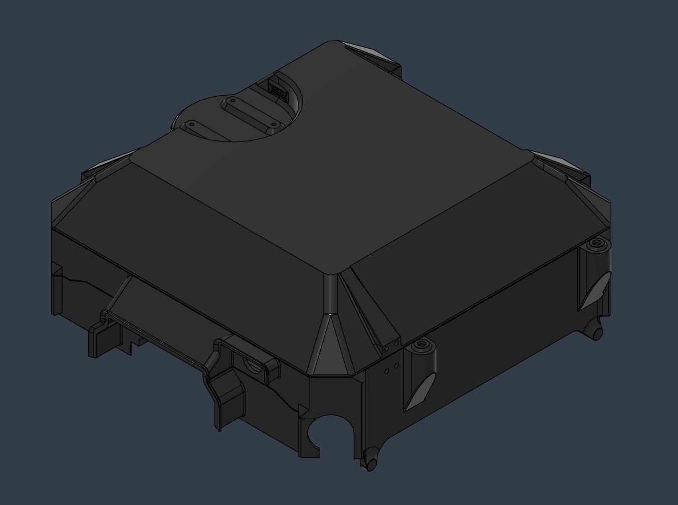
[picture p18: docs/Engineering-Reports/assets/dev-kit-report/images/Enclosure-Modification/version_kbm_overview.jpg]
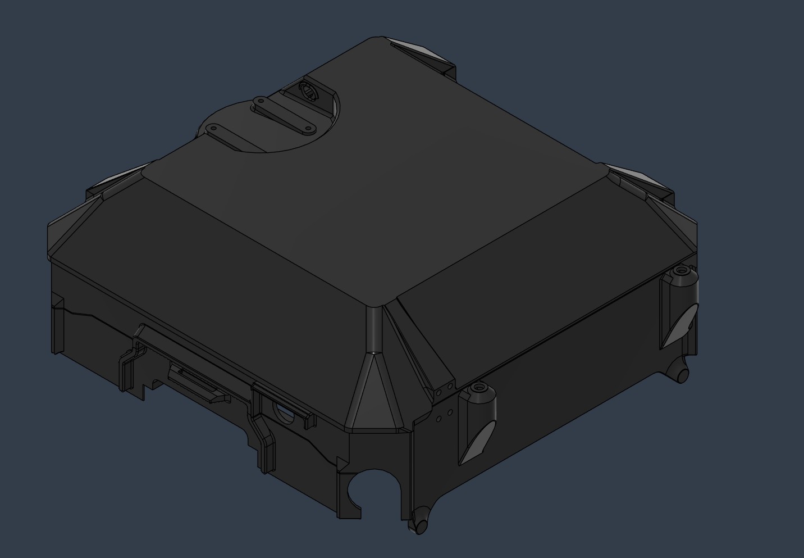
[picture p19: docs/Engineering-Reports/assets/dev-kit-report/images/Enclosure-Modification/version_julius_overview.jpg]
|  |  |
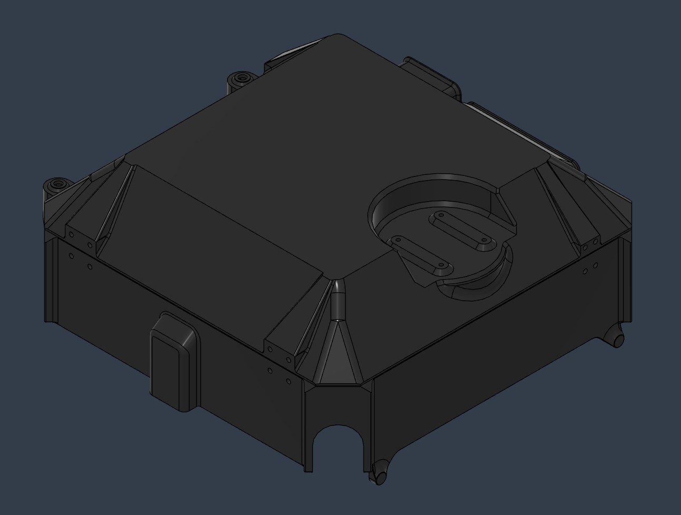
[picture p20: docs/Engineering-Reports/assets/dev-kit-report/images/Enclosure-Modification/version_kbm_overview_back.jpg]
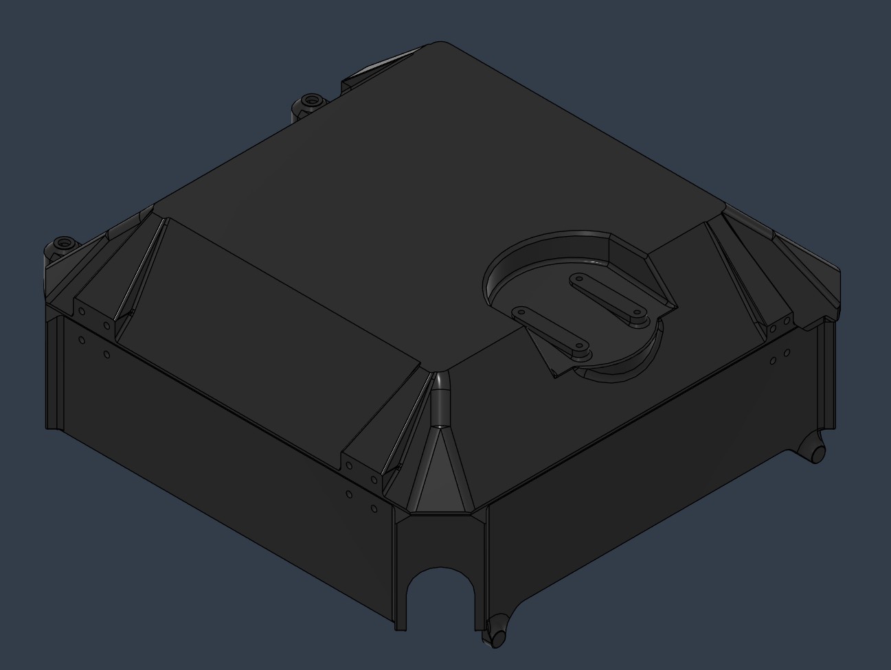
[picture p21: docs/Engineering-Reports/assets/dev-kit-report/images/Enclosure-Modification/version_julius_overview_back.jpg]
|  |  |

**Cable Anchors**

New curved cable anchors compatible with zip ties and large cables were integrated throughout the enclosure interior. The anchor geometry is optimized for supportless 3D printing. The total number of anchors exceeds current requirements, providing spare capacity for future wiring additions.

| Version 1 | Version 2 |
| :---: | :---: |
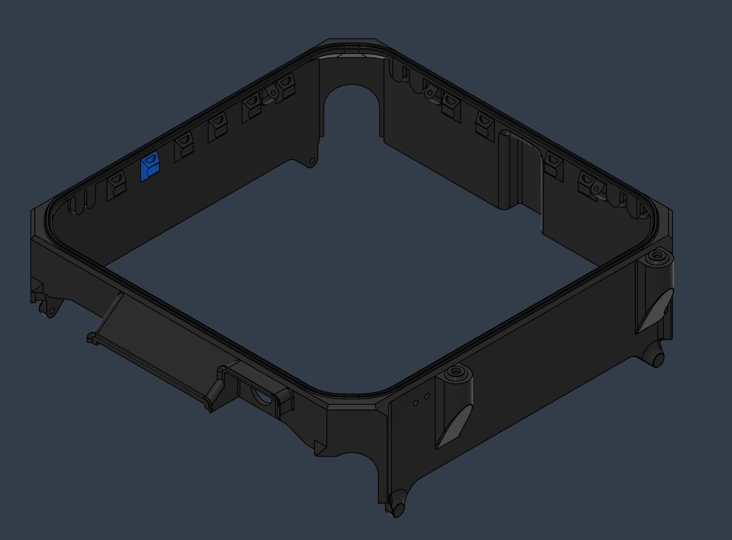
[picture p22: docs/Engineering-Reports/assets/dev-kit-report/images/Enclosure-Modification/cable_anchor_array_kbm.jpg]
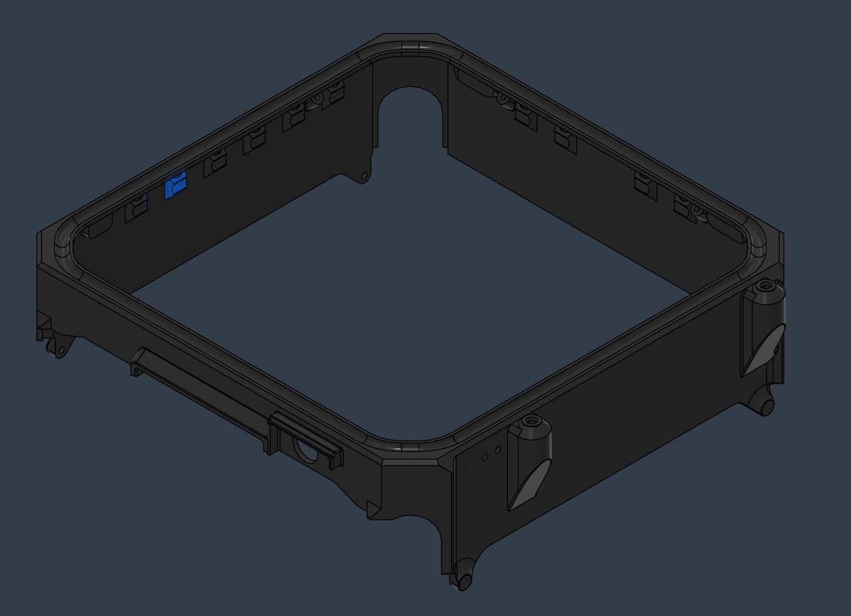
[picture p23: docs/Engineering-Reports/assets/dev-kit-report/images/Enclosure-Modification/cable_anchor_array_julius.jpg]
|  |  |

**Embedded LiDAR Mount**

The cockpit lid incorporates a dedicated mounting slot for the SLAMTEC RPLidar S2L 360° LiDAR module. The slot minimizes the module's height profile above the lid while preserving the full optical path of the laser beam. Drainage gaps and cable outlets are sized to pass the full LiDAR electrical connector and are compatible with sealant application.

| Version 1 | Version 2 |
| :---: | :---: |
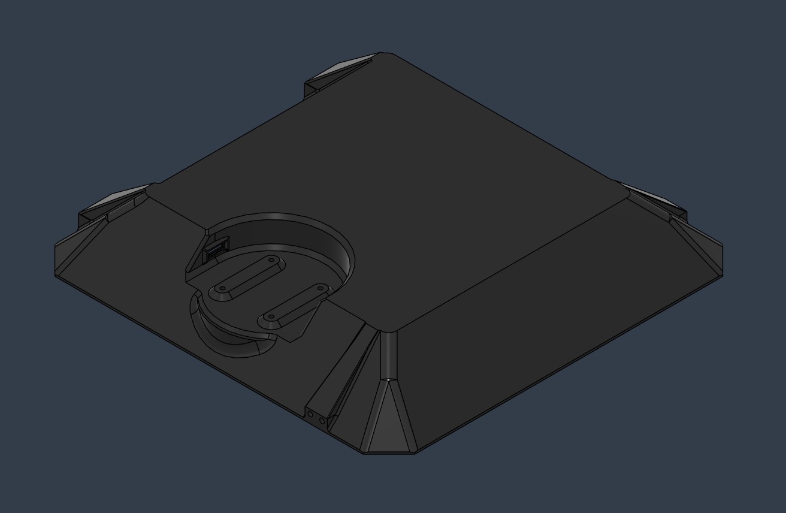
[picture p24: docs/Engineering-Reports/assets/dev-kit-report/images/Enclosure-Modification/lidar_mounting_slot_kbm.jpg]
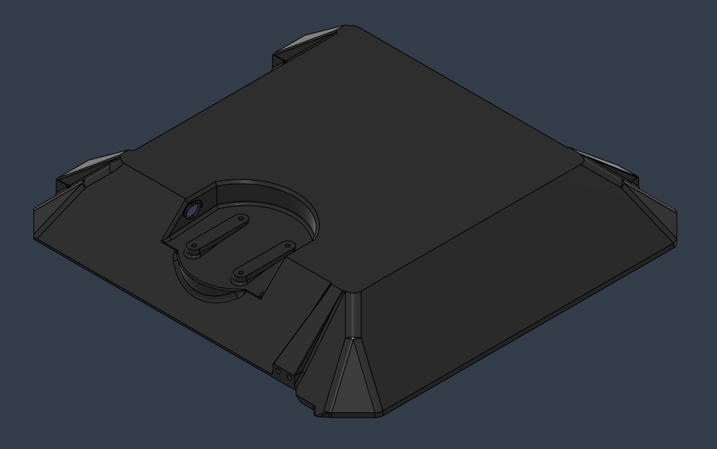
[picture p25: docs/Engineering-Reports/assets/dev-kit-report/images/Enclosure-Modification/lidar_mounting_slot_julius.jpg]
|  |  |

**Cockpit Latch Replacement**

The original 3D printed latches were replaced by stainless steel draw latches (McMaster-Carr 6082A11) on both sides of the lid for improved long term reliability.



**Module Mounting Plate**

A triangular floating mounting plate was added to the main enclosure's inner corner to secure the Ethernet adapter and Remote ID beacon module. The plate is interchangeable between left and right sides of the aircraft (note: not interchangeable between Version 1 and Version 2 due to geometry differences). Screw insert bases are angled at 45° for maintenance access and supportless 3D printing.

| Assembly view | Isolated view |
| :---: | :---: |
|  |  |

**3D Printing Size Optimization (Version 2)**

The enclosure total length was reduced from 34.7 cm to 31.4 cm by shortening the battery rain shield and front cable outlet, enabling the enclosure to fit on a wider range of consumer 3D printers.

| Version 1 (34.7 cm) | Version 2 (31.4 cm) |
| :---: | :---: |
|  |  |

#### Weight Reduction Study

A weight reduction study was conducted by reducing the material thickness of aluminum airframe plates and evaluating the structural impact through FEA simulation and physical flight testing.

**Proposed reductions:**

| Part | Original | Proposed |
| :--- | :--- | :--- |
| 1101-UpperPlate | 2 mm | 1 mm |
| 1102-MidPlate | 2 mm | 1 mm |
| 1103-LowerPlate | 4 mm | 2 mm |
| 1211-CW_Long | 2 mm | 1 mm |
| 1212/1213-Square_Short | 2 mm | 1 mm |
| 1221/1222-Wall | 2 mm | 1 mm |

**FEA results:** The lower airframe parts (1221/1222-Wall and 1103-LowerPlate) exhibited significant deformation under a 300 N lateral static force when thinned. The upper airframe parts remained rigid.



_FEA displacement under a 300 N lateral static force at the lower frame (unit: mm)._

**Flight testing results:**
- *Without payload:* Flight behavior appeared normal on visual inspection, but log analysis showed increased lateral vibrations from wall movement.

  | | |
  | :---: | :---: |
  |  |  |

  _Lateral deformation of the lower frame walls visible during physical inspection._

- *With maximum payload (~7 kg):* The flight had to be aborted due to strong oscillations. The thinned lower frame was no longer rigid enough under payload weight, causing the flight controller to continuously counteract frame induced instability.

**Final decision:** Thickness reduced for the upper airframe parts. Lower airframe and battery bay parts remain at original thickness.

| Part | Final Thickness |
| :--- | :--- |
| 1101-UpperPlate | 1 mm (reduced) |
| 1102-MidPlate | 1 mm (reduced) |
| 1211-CW_Long | 1 mm (reduced) |
| 1212/1213-Square_Short | 1 mm (reduced) |
| 1103-LowerPlate | 4 mm (unchanged) |
| 1221/1222-Wall | 2 mm (unchanged) |



_Final configuration: upper airframe thinned, lower frame and battery bay at original thickness._

#### Transport Case

The transport solution for the Dev-Kit is a used Pelican 1640 rolling case with custom laser cut foam inserts, selected after a custom hard case was found to be incompatible with the airframe form factor. A 3D printed camera cap protects the gimbal camera during transport.



_Quiver loaded in the Pelican 1640 transport case._

#### Detachable Landing Gear

25 mm diameter landing gear was tested first and subsequently upgraded to a custom 30 mm diameter variant manufactured by RJX Hobby. A 120-unit batch order was placed in January 2026.

#### Altitude Sensor Mount Redesign

The altitude sensor mount was fully redesigned to accommodate the two new sensor modules (Ainstein US-D1 radar altimeter and Benewake TF03-180 LiDAR altimeter) and to simplify the wiring process of the previous design.

The new mount uses an X-pattern upper structure for weight reduction and improved 3D printing sliceability. The pattern also provides natural cable organization for altitude sensor wiring. Screw insert bases for the forward facing radar use large chamfers to enable supportless 3D printing.

The SIYI gimbal camera was repositioned to the right side of the aircraft. The installation method is unchanged from the PT3 design.

| Design | Installed |
| :---: | :---: |
|  |  |

---

### <ins>Electronics Integration</ins>

#### PCB Vibration Isolation Mount

The Main PCB is secured to a custom 3D printed PETG-CF adapter plate, which mounts to the aluminum upper plate through five rubber vibration dampeners. The mount floats entirely on the dampeners and must not make contact with the aluminum frame at any point — any direct contact defeats the isolation. This decouples high frequency motor and propulsion vibrations from the PCB assembly and flight controller sensors.



One design constraint to note: the through-hole pins of the DC-DC converters on the underside of the Main PCB extend far enough to puncture the adapter plate or short against the frame if not trimmed before installation.

#### Battery PCB Updates

The Battery PCB was updated with the following changes:



**MOSFET upgrades** (higher power ratings):
- Q1: Pre-charge MOSFET
- Q8: 12V control MOSFET
- Q9: Bypass MOSFET

**Protection and routing:**
- Protection diodes D10 and D11 added
- Main power output cables replaced with copper bus bars for improved current capacity and mechanical reliability
- Second SSR signal added on J3 (connector 1778735) for redundancy
- Silkscreen updated to reflect correct pushbutton wiring

#### Main PCB Updates

The Main PCB is the central hub routing power and signals between the flight controller and all major subsystems, including payload ports, sensors, the Raspberry Pi, telemetry units, and Ethernet infrastructure. The Dev-Kit revision built on the PT3 first revision with the following improvements:

| Front | Back |
| :---: | :---: |
|  |  |

**Connector updates:**
- Switched to JST-GH connectors for HM30 Air Unit (J15, J17), auxiliary CAN connections (J18, J20, J22), and GNSS (J5, J7)
- Dedicated 360° LiDAR connector added (U5)

**Power system:**
- New "Power Supply" schematic sheet added for 5V and 12V supplies
  - Capacitors C2, C9, C13, C16 added to PS1; C8, C10, C14, C17 added to PS2
  - Backup 5V supply added (U4) for flight controller redundancy
- New "Power Control" schematic sheet added for payload/HV switching
  - Updated control scheme using a CPC1019N SSR to drive a high power MOSFET
  - Fuses, LED indicators, and protection circuitry added (see schematic for full detail)

**Redundancy:**
- Redundant SSR control trace added: J46 Pin 5 (IO_CH5_Backup) provides a backup signal path to prevent signal loss

**Mechanical integration:**
- SMD-soldered threaded standoffs added for GNSS (U3, U6–U8), Raspberry Pi (U9–U12), and Ethernet switches (U13–U16)

**Layer strategy:** The 6-layer PCB layout uses dedicated layers for power routing, CAN bus, and Ethernet signals.

#### Attachment Interface PCB

The Attachment Interface PCB provides the electrical interface between the Main PCB and each of the three payload ports (C1, C2, C3). It routes regulated 12V power, CAN bus signals, and Ethernet (on C1 and C2) from the Main PCB to the payload through pogo-pin contacts at the quick-release attachment point. The board is designed for hot swap operation, allowing payloads to be connected and disconnected without disturbing the main electronics stack.

The Dev-Kit introduced a revised version of the Attachment Interface PCB (V1.4) focused on manufacturability and mechanical interfacing improvements. All original functional characteristics are retained.

The primary change replaces the J2 and J3 connectors with individual spring loaded pin headers (U1–U20), with enlarged solder pads on the corresponding contact side to improve the interface with the pogo pins at the quick-release attachment point. Solder pads across the board were extended to improve assembly robustness, PCB routing was updated to use rounded trace edges, and an orientation notch was added to the silkscreen to reduce assembly ambiguity.

| | | |
| :---: | :---: | :---: |
|  |  |  |

For detailed design documentation, refer to the [Attachment Interface PCB V1.4 Information Note](https://github.com/Arrow-air/project-quiver/blob/main/task-grant-bounty/pt3/electronics/0003-Attachment-Interface-PCB/2026-Update/information-note.md).

#### Raspberry Pi Integration

The Raspberry Pi 4/5 companion computer is mounted directly on the Main PCB via the SMD threaded standoffs. It serves as the intelligent bridge between the flight controller, payload ports, and Quiver Hub.

During Dev-Kit development, the following integrations were validated:
- Battery data visualization via MAVSDK web interface
- REST File Get Client for bidirectional communication with Quiver Hub
- RPLidar C1 terrain mapping payload pipeline (end to end from sensor to browser visualization)
- Obstacle avoidance parameter management via Lua scripting on ArduPilot

The 5V power supply on the Main PCB was upgraded to support the power budget of the Raspberry Pi and a 4G/LTE cellular modem simultaneously.

#### Ethernet Integration

Two GigaBlox Nano 1-inch Gigabit Ethernet switches are installed on the Main PCB, providing Ethernet connectivity to the three payload ports (C1, C2, C3) and to the flight controller via the CubeNode ETH DroneCAN to Ethernet adapter.

**Network topology (drone subnet: 192.168.144.x):**

All onboard devices share a flat 192.168.144.0/24 network. Several addresses are hardcoded by SIYI hardware firmware and cannot be reconfigured — all other device assignments must avoid these reserved addresses.

**Quiver device assignments:**

| Device | IP Address |
| :--- | :--- |
| CubeNode ETH adapter | 192.168.144.10 |
| Raspberry Pi (companion computer) | 192.168.144.50 |
| Flight Controller | 192.168.144.51 |
| Payload bottom port (C1) | 192.168.144.100 |
| Payload side port 1 (C2) | 192.168.144.101 (default, see note) |
| Payload side port 2 (C3) | 192.168.144.102 (default, see note) |
| Ground station laptops / dev machines | 192.168.144.200–254 |

**SIYI reserved addresses (do not use):**

| IP Address | Device |
| :--- | :--- |
| 192.168.144.11 | SIYI air unit |
| 192.168.144.12 | SIYI ground unit |
| 192.168.144.20 | Android ground station (SIYI) |
| 192.168.144.25 | SIYI A8 Mini camera |
| 192.168.144.60 | SIYI cameras (reserved, unused) |

Payload and attachment developers should assign static IPs in the 192.168.144.100–199 range. Earlier SDK documentation assigned C1=.11, C2=.12, C3=.13 — those addresses conflict with SIYI hardware and should not be used.

> [!NOTE]
> **On side port IPs:** The bottom port assignment (.100) is fixed because that port is always the bottom. Side port assignments (.101/.102) are defaults based on physical port position. Attachments designed to work on either side port should treat their IP as a configurable parameter rather than a hardcoded value, so operators can reassign it to match whichever port the attachment is actually mounted on.

The switches are secured to the Main PCB using M2x6 screws. Dev-Kit PCBs have spacers already soldered; older PCBs require a separate spacer and nut.

#### Remote ID Integration

A DroneBeacon db201 (Bluemark) is mounted inside the main enclosure on the floating module mounting plate alongside the Ethernet adapter. The module runs ArduRemoteID firmware on an ESP32 processor and broadcasts operator and drone identity over WiFi and Bluetooth Low Energy simultaneously. Integration was validated on April 10, 2026 running ArduCopter V4.7.0-dev on the Pix32 v6, connected via DroneCAN.

Remote ID requires the Quiver custom ArduPilot firmware build (PR #183, `feature/firmware-docs-v2`), compiled with `AP_OPENDRONEID_ENABLED=1`. Stock ArduPilot firmware does not include this capability. Operator and drone IDs are configured per operator via Mission Planner or automated through a Python script running as a systemd service on the Raspberry Pi.

**GCS GPS requirement:**

The flight controller requires a GCS GPS fix to pass the "operator location must be set" pre-arm check. Laptops without built in GPS can satisfy this using an Android phone running GPS NMEA Tether, which streams NMEA data to Mission Planner over Bluetooth SPP. During indoor validation, 25–28 satellites were received via this method. GCS GPS HDOP is elevated indoors, which produces a yellow status indicator and is expected to resolve with an outdoor fix.

**Bluetooth scan validation:**

A BLE scan using a Remote ID scanner app (OpenDroneID / DroneScanner) confirmed the following fields broadcast correctly:

| Field | Status | Notes |
| :--- | :--- | :--- |
| UAS ID (Serial Number) | Visible | |
| Operator ID | Visible | |
| UA Type | Visible | Helicopter/Multirotor |
| Self ID / Description | Visible | Free-text field |
| Drone location (lat/lon/alt) | Visible | From FC GPS |
| Operator location | Visible | From GCS GPS |
| Manufacturer / Model | "Unknown" | See note |

The "Unknown" manufacturer field is not populated by ArduRemoteID firmware and cannot be configured. This field is optional under ASTM F3411 and the EU Remote ID standard and has no compliance impact.

Remote ID integration is validated. Per unit configuration is required before shipment to each operator: `UAS_ID` must be set to the registered serial number and `Operator ID` to the operator's CAA registration. Both FAA Part 107 compliance (US) and EASA Open Category operations (EU) require this configuration to be completed.

---

### <ins>Software Upgrades</ins>

#### Quiver Hub

Quiver Hub is a web application that serves as the ground control and data operations center for the Quiver ecosystem. It is built around a three tier architecture: a browser based frontend, a Node.js server handling API, real time streaming, persistence, and job orchestration, and an onboard companion computer fleet running relay and job execution services. Sensor data from drones flows up to Hub for display and storage through REST ingestion endpoints. Commands from operators flow down through a job queue to the companion computer for local execution. Real time data distribution to the browser uses WebSocket streaming. Browser to server operations use typed RPC.

**Implemented:**

- **LiDAR Visualization**: Real time 2D and 3D display of RPLidar point cloud data as it arrives from the drone. Includes a demo mode for offline testing without a live sensor.
- **Flight Telemetry**: Live dashboard showing attitude, position, GPS state, and battery status from both the flight controller and the smart battery.
- **Camera and Gimbal Control**: Live video stream from the SIYI A8 camera to the Hub interface, validated in March 2026, with controls that relay gimbal commands through the companion computer.
- **Flight Analytics**: Post-flight log analysis using ArduPilot DataFlash logs parsed client-side in the browser, with charts covering attitude, navigation, power, vibration, radio link, and EKF state. Includes a flight mode timeline, side by side log comparison, and summary export.
- **Drone Configuration**: Fleet management covering drone registration, API key management, connection testing, file upload to the companion computer, and job dispatch.
- **Developer extensibility**: App Store and App Builder framework for publishing custom data pipeline applications. Supports custom ingestion endpoints, server side Python payload parsing, and UI widgets bound to live data streams. App versioning and rollback are included.
- **Flight Log Module (Logs v1)**: Full FC to companion to Hub log pipeline. Operators can trigger a scan job, browse discovered logs, request downloads from the flight controller, store retrieved logs in Hub, download them through the browser, and forward completed logs into analytics workflows.
- **OTA Update Module (OTA v1)**: Firmware upload with SHA-256 hashing, staged delivery through the companion computer, companion-side integrity verification before flashing, and flash execution on the flight controller. Includes Hub side listing, upload, job request, and failed record cleanup.
- **Security baseline**: Artefact integrity verification enforced at flash time via SHA-256 hash comparison. Job reliability layer implemented covering retry handling, expiry, timeout reaping, locking, and cleanup for stuck or failed work. Job allow listing and permissions hardening are sequenced as follow-on work alongside the broader SDK integration layer.
- **Diagnostics and Remote Logs**: Dedicated views for flight controller logs, OTA update status, diagnostics, and remote log access.

**Remaining development:**

- Job allow-listing and typed job permissions hardening
- Mission Planner UI
- Standalone local deployment and hosted SaaS deployment strategies
- Multi-user and fleet scaling validation
- Database migration tooling and operational backup strategy

#### Quiver Payload SDK

The Quiver SDK is a Python development toolkit for companion computer and payload integration. A formal architecture specification was drafted in March 2026 and the SDK was published to its own repository in April 2026. The features described below are planned; none of the formal SDK packages are implemented yet. The existing telemetry forwarder and job runner scripts on the Raspberry Pi predate the SDK spec and will eventually be replaced by it.

**Planned architecture:**

The SDK is designed as two separate packages. `quiver-sdk` is the core hardware abstraction layer, providing Python interfaces for vehicle control via MAVLink, camera and gimbal operation, and communication with payload devices over Ethernet and CAN. It is designed to run on the onboard Raspberry Pi or any machine on the drone network and does not require internet connectivity. `quiver-hub` is a separate integration layer that imports `quiver-sdk` and adds telemetry forwarding to Quiver Hub, a job runner for executing remote commands, and a payload data streamer. Developers building onboard autonomy only need `quiver-sdk`. Developers building Hub-integrated applications install both.

For the MAVLink layer, pymavlink was selected over MAVSDK on the basis that Quiver runs ArduCopter and pymavlink is maintained by the same team, exposing all ArduPilot-specific messages. ROS2 integration was considered but placed out of scope for the v1 release.

**Development roadmap:**

Nine milestones cover the full SDK delivery:

- M1–M2: Vehicle control and camera interfaces validated on real hardware
- M3–M5: Payload attachment API covering raw device communication, typed streams, and the payload contract specification
- M6–M7: `quiver-hub` layer replacing the existing telemetry forwarder and job runner scripts
- M8: Payload data streaming integrated with Hub App Builder
- M9: PyPI publication, systemd service templates, and developer documentation

**Existing proof of concept:**

Prior to the formal SDK specification, a terrain mapping pipeline was implemented and validated:

```
RPLidar C1 → Raspberry Pi (TCP, 10 Hz) → HTTP POST → Quiver Hub → Browser (WebSocket)
```

- Scan rate: 8–12 Hz (target 10 Hz)
- Points per scan: 250–500 (typical ~350)
- End to end latency: ~100–150 ms

This pipeline informed the SDK architecture and serves as the reference implementation for the payload streaming layer.

GitHub: https://github.com/Arrow-air/quiver-sdk

#### Obstacle Avoidance Selection, Tuning, and SITL Simulation

**Sensor configuration:**

| Sensor | Coverage | Range | Role |
| :--- | :--- | :--- | :--- |
| RPLidar S2L | 360° horizontal | ~18 m | Primary proximity input to BendyRuler |
| NanoRadar MR82 | Forward sector | ~30 m | Supplemental forward detection in degraded conditions |
| Barometer + Rangefinder | Vertical | — | Altitude estimation and terrain clearance |

**ArduPilot custom firmware:**

The RPLidar S2L is not natively supported in upstream ArduPilot. The Dev-Kit operates on a custom ArduPilot build incorporating an in house sensor driver extension. The patch is limited to driver support and proximity interface integration, with no modifications to core navigation or avoidance algorithms. An upstream pull request has been submitted: https://github.com/ArduPilot/ardupilot/pull/31663

**Obstacle avoidance algorithm: BendyRuler (`OA_TYPE = 1`)**

Proximity database:

| Parameter | Value | Description |
| :--- | :--- | :--- |
| `OA_DB_SIZE` | 100 | Max stored obstacle points |
| `OA_DB_QUEUE_SIZE` | 80 | Queue depth for incoming data |
| `OA_DB_EXPIRE` | 3 s | Obstacle point expiry time |
| `OA_DB_OUTPUT` | 3 | Output mode |
| `OA_DB_BEAM_WIDTH` | 10° | Angular obstacle representation width |
| `OA_DB_RADIUS_MIN` | 0.2 m | Minimum obstacle radius |
| `OA_DB_DIST_MAX` | 10 m | Maximum distance for obstacle storage |

BendyRuler motion constraints:

| Parameter | Value | Description |
| :--- | :--- | :--- |
| `OA_BR_TYPE` | 1 | BendyRuler enabled |
| `OA_BR_LOOKAHEAD` | 12 m | Forward projection distance |
| `OA_BR_CONT_RATIO` | 1.2 | Continuity weighting |
| `OA_BR_CONT_ANGLE` | 60° | Max directional change |
| `OA_MARGIN_MAX` | 4 m | Minimum clearance from obstacles |
| `OA_OPTIONS` | 1 | Basic avoidance features enabled |

The 4 m obstacle margin is intentionally set low to allow maneuvering within tree dense environments where larger margins prevent feasible path planning. Dynamic margin scaling as a function of ground speed is under investigation.

**SITL simulation:**

A Software in the Loop simulation environment was established using the same ArduPilot branch and parameter set as the flight hardware. An SF45 LiDAR model substitutes for the RPLidar S2L. The environment is launched with:

```bash
../Tools/autotest/sim_vehicle.py --map --console \
  -A "--serial5=sim:sf45b --serial6=sim:obstacle"
```

SITL results are used to identify safe parameter ranges and inform flight test planning. They are not a substitute for real hardware validation.

| | |
| :---: | :---: |
|  |  |

_QGroundControl views of the SITL obstacle avoidance simulation._

**Flight testing roadmap:**

| Phase | Environment | Focus |
| :--- | :--- | :--- |
| 1: Sensor Checks | Open field (Texas) | Sensor alignment, 360° yaw test, person with board obstacle |
| 2: Manual Control | Open field | Circling, stick disturbance, narrow gate, payload impact |
| 3: AUTO Missions | Open field | Waypoint missions with single and dual obstacles |
| 4: Dense Environments | Germany (trees) | Parameter validation with Texas baseline settings |

Pass criteria:
- Zero obstacle contact
- At least 95% AUTO mission success rate
- Separation of at least `OA_MARGIN_MAX` − 1 m at all times

**Known issue:** As of March 2026, the S2L LiDAR exhibits intermittent dropouts during flight, despite reliable ground performance. Suspected cause is vibration resonance or electrical load interaction. Under active investigation.

---

## Weight & Payload Summary

### Configuration Summary

| Configuration | Battery | Battery mass | Empty weight | AUW | Payload capacity |
| :--- | :--- | :--- | :--- | :--- | :--- |
| Standard | 20Ah LiPo (14S) | 7.90 kg | 9.65 kg | 17.55 kg | **7.45 kg** |
| Long endurance | 30Ah LiPo (14S) | 11.40 kg | 9.65 kg | 21.40 kg | **3.95 kg** |
| MTOW limit | — | — | — | **25.00 kg** | — |

Payload capacity = MTOW − empty weight − battery mass. MTOW is 25 kg per the intended regulatory category.

### Subsystem Breakdown

Empty weight covers the full Dev-Kit build as shipped, including the NanoRadar MR82 forward-facing radar (92 g) and attachment interface cables (~100 g). Battery is excluded.

| Subsystem | Items | Mass |
| :--- | :--- | :--- |
| Airframe Structure | Upper/mid plates, lower plate, motor arms, CF tubes, landing gear | TBD |
| Propulsion | 4× XRotor X6 PLUS (motor + ESC + props, 790 g each) | **3.16 kg** |
| Avionics & Sensors | Pix32 v6 (36 g), RPLidar S2L (190 g), NanoRadar MR82 (92 g), Ainstein US-D1 (110 g), Benewake TF03-180 (89 g), Holybro F9P (60 g), Mateksys M9N (16 g), SIYI A8 mini (95 g), SIYI HM30 air unit (74 g), DroneBeacon db201 (4 g), sensor mount (TBD) | TBD (≥ 766 g) |
| Custom PCBs | Main PCB, Battery PCB, FC PCB, 3× Attachment Interface PCB | TBD |
| Companion Computer | Raspberry Pi 5 (47 g), 2× GigaBlox Nano (18 g each), CubeNode ETH (7 g) | **90 g** |
| Enclosure & Mounts | Enclosure body, cockpit lid, PCB vibration mount, module plate | TBD |
| Harness | Wiring, connectors, attachment interface cables | TBD |
| Hardware & Fasteners | Screws, standoffs, grommets, misc | TBD |
| **Total empty weight** | | **9.65 kg** |

---

## Performance Metrics & Endurance Testing

The Dev-Kit performance evaluation follows a standardized methodology for comparing prototypes across control behavior, stability, efficiency, and navigation accuracy. Metrics are extracted from ArduPilot flight logs using Mission Planner, MAVExplorer, and custom scripts. Tests cover rate tracking error, vibration analysis, power efficiency, climb performance, yaw authority, waypoint tracking, and glide capability. Results are collected under consistent environmental and configuration conditions to ensure fair comparisons.

**PENDING TEST RESULTS** — Endurance and performance metrics flight testing is planned for May 2026 / ongoing.

---

## Beta Testing

External field testing of the first Dev-Kit units is planned following endurance flight validation, completion of the documentation suite, and GPS/4G RF interference investigation. Target beta operators have been identified.

**PENDING**

---

## Conclusions & Future Recommendations

The Dev-Kit phase achieved its primary objective of converting the PT3 prototype into a shippable developer platform. The structural, electronics, and software work are well integrated, and the weatherproofing validation, vibration isolation, and obstacle avoidance integration represent meaningful advances over PT3.

The most important lesson from this phase concerns structural weight reduction under payload. The decision to keep lower airframe plates at original thickness came from a flight test result that FEA did not fully predict. The thinned lower frame was airworthy without a payload but unsafe with one. This validates the need to test structural changes at the weight conditions the aircraft will actually operate under, not just at empty weight.

On the software side, the terrain mapping pipeline served as a proof of concept that informed the SDK architecture. Quiver Hub's App Store and App Builder framework provides an extensibility path for payload developers, though the developer documentation required to make that accessible is still in progress.

The obstacle avoidance system is the most analytically complete subsystem in the Dev-Kit: SITL validated parameters, a structured four phase test roadmap, clear pass criteria, and a documented known issue. The approach of running SITL analysis before field testing proved useful and should be applied to future subsystem work.

Remote ID integration was validated in April 2026 via DroneCAN, clearing the last hardware blocker ahead of external shipments. Per operator configuration of the UAS ID and operator credentials is required before each unit ships, which is an operational step rather than an open engineering item.

**Open items heading into field deployment:**
- Endurance and performance metrics flight validation (planned May 2026)
- Obstacle avoidance field testing across four phases
- LiDAR dropout root cause analysis (suspected vibration or electrical load interaction)
- GPS/4G RF interference investigation and resolution
- Actuated payload latch mechanism (bounty in progress)
- Multispectral camera payload (bounty in progress)
- EASA C3 certification pathway (deferred, estimated €17k–20k)

---

## Appendices

### Dev-Kit Information Notes

- [Main PCB Update](https://github.com/Arrow-air/project-quiver/blob/main/task-grant-bounty/Dev-Kit/Main-PCB-Update.md)
- [Battery PCB Update](https://github.com/Arrow-air/project-quiver/blob/main/task-grant-bounty/Dev-Kit/Front-PCB-Update.md)
- [PCB Vibration Mount](https://github.com/Arrow-air/project-quiver/blob/main/task-grant-bounty/Dev-Kit/PCB-Vibration-Mount.md)
- [Comprehensive Main Enclosure Modification](https://github.com/Arrow-air/project-quiver/blob/main/task-grant-bounty/Dev-Kit/Comprehensive-Main-Enclosure-Modification.md)
- [Structure Weight Reduction](https://github.com/Arrow-air/project-quiver/blob/main/task-grant-bounty/Dev-Kit/Structure-Weight-Reduction.md)
- [Improvement of Dust and Water Resistance](https://github.com/Arrow-air/project-quiver/blob/main/task-grant-bounty/Dev-Kit/Improvement-of-Dust-and-Water-Resistance.md)
- [Sensor Mount Re-modeling](https://github.com/Arrow-air/project-quiver/blob/main/task-grant-bounty/Dev-Kit/Sensor-Mount-Remodeling.md)
- [Obstacle Avoidance](https://github.com/Arrow-air/project-quiver/blob/main/task-grant-bounty/Dev-Kit/Obstacle-Avoidance.md)
- [SITL Evaluation](https://github.com/Arrow-air/project-quiver/blob/main/task-grant-bounty/Dev-Kit/SITL-Evaluation.md)
- [Ethernet Setup Guide](https://github.com/Arrow-air/project-quiver/blob/main/task-grant-bounty/Dev-Kit/Ethernet-Setup-Guide.md)
- [Quiver Hub V1 (M1–M3)](https://github.com/Arrow-air/project-quiver/blob/main/task-grant-bounty/Dev-Kit/Quiver-Hub-v1.md)
- [Quiver SDK](https://github.com/Arrow-air/project-quiver/blob/main/task-grant-bounty/Dev-Kit/Quiver-SDK.md)
- [Quiver SDK Test](https://github.com/Arrow-air/project-quiver/blob/main/task-grant-bounty/Dev-Kit/Quiver-SDK-Test.md)

### Previous Engineering Reports

- [PT1](https://github.com/Arrow-air/project-quiver/blob/main/docs/Engineering-Reports/PT1-Engineering-Report.md)
- [PT2](https://github.com/Arrow-air/project-quiver/blob/main/docs/Engineering-Reports/PT2-Engineering-Report.md)
- [PT3](https://github.com/Arrow-air/project-quiver/blob/main/docs/Engineering-Reports/PT3-Engineering-Report.md)

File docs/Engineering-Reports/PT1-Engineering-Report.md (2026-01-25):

---
title: PT1 Engineering Report
sidebar_position: 1
description: Engineering report for Project Quiver Prototype 1
---

# Project Quiver PT1 Engineering Report

| | |
|---|---|
| **Authors** | 21stCenturyAlex, alperenag, errrks.eth, Julius, Dow Fisher KBM, ZeynepB |
| **Editor** | errrks.eth |
| **Date** | April 2025 |

PT1 Hero

---

## 1. Introduction

The purpose of Project Quiver is to design and manufacture a practical multi-purpose multi-rotor unmanned aerial vehicle. This aligns with Arrow’s mission of developing manned and unmanned aircraft for the commercial aviation market while generating new concepts in manufacturing, materials science, structural design, and related technologies. Equipped with internet native collaborators and Web3 infrastructure, Arrow aims to break up the lack of innovation in the global drone market.   

This aircraft is designed to perform typical light UAV missions. The design concept is: compact and portable, easy to manufacture, easy to maintain, highly reliable, highly adaptable, and expandable.

The First Prototype (PT1) of Project Quiver will feature:
- A common quadcopter layout to ensure energy efficiency and simplified structure.
- Maximum mission load of 25 kg. Considering the safety factor, the designated maximum thrust force is about 45 to 50 kg.
- Foldable motor beams and propellers for ease of storage and transportation.
- Standardized quick-release mission equipment pylon (Attachment interface).
- Digital autopilot system assisted features, such as GNSS-assist hovering, waypoint missions, radar altimeter, etc.
- FPV camera with video transmission to assist pilot decision and various mission actions.
- Powered with 14-cell LiHV smart battery and advanced main power connectors commonly used by heavy drones.
- CAN bus for signal communication to avoid electromagnetic interference that traditional non-differential signals such as PWM may be subject to.
- Using digitalized sensor communication to monitor more components, such as battery cell temperature and ESC temperature.
- ~~Using integrated thrust terminal to improve the reliability and design convenience of the thrust system, also for easier sourcing, installing and initial testing.~~
- single source, fully integrated motor arm with propulsion system for easier sourcing, installation, and testing. 
- Implement testbed PDB and contactor from Project Feather for safe operation of the power distribution system.

Based on these characteristics, Project Quiver will also compete with other UAVs in the market in terms of parameters such as endurance, empty weight ratio, open source development, and mission equipment. It's also expected to gradually introduce more advanced designs including but not limited to the following items in future prototypes: The following features will be introduced in future prototypes:
- Real-Time Kinematic (RTK) high-precision GNSS positioning
- Dedicated PDB
- Custom battery pack
- Custom ESC
- Integrated 3D printed structure
- Hazard protect airframe
- Multiple mission attachment interfaces
- Retractable landing gear
- Emergency ballistic parachute
- LiDAR navigation
- Dedicated ground control software
- etc.

PT1 is neither water nor dustproof and includes a single standardized attachment interface on the cockpit’s underside. The flight controller unit (FCU) remains exposed atop the battery enclosure for simplicity.

The initial mission equipment, a standardized quick-release "Brush Pod" herbicide dispenser, is designed for commercial aerial vegetation management.

Project Quiver utilized Onshape and Fusion 360 for structural design, layout, and finite element analysis (FEA). Flexible software selection enabled team members to leverage their preferred tools and workflows, facilitating interoperability through STEP and similar formats.

<!-- Chinese origin 中文原文（未纠错和润色）

Project Quiver的目的是设计并制造一款实用性多用途多旋翼无人飞行器，其目的是为了推动Arrow去中心化组织探索商业航空服务市场、为后续无人和载人飞行器型号的制造流程产生新的概念，探索新型材料、新型结构、新型通讯协议等相关技术。并尝试使用互联网协作和去中心化金融，打破现今美国乃至全世界无人机市场缺乏创新的局面。  
  
本飞行器设计为执行典型的轻型无人机任务，设计理念是：紧凑便携、易制造、易维护、高可靠、高适应、可拓展。  
  
此工程的PT1原型机将具有以下特点：  
- 采用常见的四旋翼布局，以确保能源效率和结构简易。
- 设计最大任务载荷为25公斤，考虑到安全裕度，设计最大拉力约为45至50公斤。
- 机臂、螺旋桨桨叶可向机舱侧面折叠，以优化收纳和运输。
- 标准化、可快拆式的任务载荷挂架（附挂接口）。
- 具备GNSS辅助悬停、航点任务、雷达高度计等数字化自动驾驶仪所支持的功能。
- 具备FPV相机和视频传输，以辅助飞行驾驶和各类任务动作。
- 采用大型无人机普遍使用的14串LiHV智能电池和先进的主电源连接器。
- 部分系统使用CAN总线进行通讯，避免PWM等传统非差分信号可能受到的电磁干扰。
- 采用数字化通讯的传感器以监视更多部件参数，例如电芯温度、ESC温度。
- 采用集成一体化动力终端，提升动力系统可靠性和设计便捷性，同时易于采购安装和初期测试。
- 采用先前为Project Feather设计的大型PDB和断路器，以提升配电系统的安全性和可控性。

基于以上特性，Project Quiver还将尝试在续航性能、空重比、开源程度、任务载荷选项等参数上与市面其他无人飞行器相角逐。并预计在未来的原型机型逐步引入包括但不限于以下内容的更先进的设计：  
- 实时动态差分（RTK）高精度GNSS定位
- 专用PDB
- 专用电池组
- 专用动力系统ESC
- 一体化3d打印结构
- 危害防护型机身
- 多载荷挂架
- 可收放起落架
- 紧急弹道降落伞
- 激光雷达导航
- 专用地面站遥测软件
- ...

初期版本并未采用防水防尘设计，机体的唯一一个装备挂点位于机舱腹部，且飞行控制器（FCU）安装在电池仓顶部并暴露在外，以方便调测。

目前首个任务装备为除草剂投放器“Brush Bullet Pod”（或称"Brush bullet dispenser"），首个实验性商业项目为与与其相对应的植被分析、空中撒放服务。“Brush Pod”将通过标准化的快拆式任务载荷挂架安装至机舱上。
  
Project Quiver的主流设计流程将使用Onshape和Fusion 360作为电脑设计软件。它们将主要用以整体布局、结构设计和有限元法分析。
由于项目未规定采用特定的工业设计软件，设计人员可以使用自身熟悉的各类软件和工作流程。所以在多个软件间工作时，将使用STEP或类似格式作为数据交换格式。

End Chinese origin 中文原文到此结束-->

----------

# 2. Project Requirements

### 2.1 Flight-Critical Systems

Project Quiver PT1 must incorporate robust and reliable flight-critical systems to ensure safe and predictable flight performance. The UAV shall feature advanced flight-control electronics that maintain stable operation under varying flight conditions and payload configurations. These systems will prioritize redundancy, allowing the drone to safely land even if certain critical components fail during flight operations.

##### Flight Controller:

The aircraft SHALL be equipped with a Pixhawk flight controller.

##### GPS Module:

The aircraft SHALL have redundant high-accuracy GPS antennas to support reliable navigation.

##### Radar Altimeter:

The aircraft SHALL include a radar altimeter for precise altitude measurements, particularly during low-altitude operations.

##### Telemetry:

The aircraft SHALL support real-time telemetry data transmission with a range of 5 km.

##### Motors:

The aircraft’s motors SHALL be capable of providing sufficient thrust to maintain hover with full payload between 50% - 60% throttle.

##### Propellers:

- The propellers SHALL be large and efficient to maximize lift and minimize power consumption.

- The propellers SHOULD be foldable, if feasible, to support ease of storage and transport.

##### ESCs:

The aircraft’s ESCs SHALL be compatible with a up to a 14S power supply, integrate with the CAN bus for precise motor control, and provide sufficient current to meet motor requirements.

### 2.2 Structural Integrity and Components

The structural frame shall leverage commercially available, off-the-shelf, or easily manufacturable components to enable rapid assembly and ease of replacement. The chosen materials must be lightweight yet strong enough to sustain heavy lift operations, accommodating considerable payload capacities without compromising durability or structural safety. Additionally, the structural configuration must allow flexibility for modifications and additions in future iterations.

##### Airframe:

The aircraft SHALL incorporate a durable carbon fiber or aluminum frame capable of supporting a maximum take-off weight (MTOW) of 25 kg and SHALL be designed to accommodate various payload configurations.

The airframe SHALL be constructed using:

-   Commonly available off-the-shelf components
    
-   Common material processing methods.

The aircraft’s motor arms SHALL be foldable to enhance portability and ease of deployment.

##### Landing Gear:

The aircraft’s landing gear SHALL be shock-absorbing and support the full MTOW during landing, including in hard-landing scenarios

##### Modular Design:

The aircraft SHALL be designed with modular, easily replaceable arms, motors, and ESCs to facilitate streamlined maintenance.

### 2.3 Electrical Systems and Power Management

A simplified and robust electrical system shall be designed, ensuring reliability and ease of troubleshooting. Commercially available battery packs must support adequate flight durations, providing sufficient power for continuous flight under maximum payload conditions. The power system should include protective features such as circuit breakers or fuses, mitigating the risk of electrical overload or failures.

##### Battery:

The aircraft SHALL use a 12S or 14S LiPo or Li-ion battery with sufficient capacity to meet endurance requirements.

##### Battery Management System (BMS):

The BMS SHALL monitor battery health, temperature, and charge/discharge rates to ensure optimal battery performance and safety.

##### HV Kill Switch:

The aircraft SHALL have a kill switch for the high-voltage electrical network.

##### LV Kill Switch:

The aircraft SHALL have a kill switch for the low-voltage electrical network.

##### Power Distribution Board (PDB):

The PDB SHALL provide stable 12S or 14S power distribution to all critical components.

##### Battery Case:

The battery SHALL be housed in a case permitting easy swap for rapid replacement in the field.

##### Charging:

The aircraft SHALL NOT require in-aircraft battery charging capabilities.

##### Hover Time Without Payload:

The aircraft SHALL provide at least 25 minutes of hover endurance without payload.

##### Battery Reserve:

The aircraft SHALL ensure a 20% battery reserve upon landing for safety considerations.

##### Cooling System:

The aircraft SHALL incorporate an effective cooling system for motors, ESCs, and the battery, if necessary, to maintain consistent performance during prolonged flights.

##### Health Monitoring:

The aircraft SHALL provide real-time monitoring of ESC and battery health.

##### Pre-Flight Diagnostics:

The aircraft SHALL include a pre-flight diagnostics system to battery levels, GPS accuracy, radar altimeter functionality, and sensor health before each flight.

##### Heading Indicator LEDs:

The aircraft SHALL include LEDs with predefined colors around it to indicate its direction.

### 2.4 Payload Integration and Imaging

The UAV prototype shall integrate a stabilized camera system mounted on a gimbal, providing steady, high-quality video feeds to ground operators. An adaptable payload attachment mechanism must enable rapid payload swaps in-field, thus maximizing versatility across various mission profiles.

##### Payload Capacity:

The aircraft SHALL be capable of carrying at least 7 kg of payload during any mission.

##### Quick-Release Mounting:

The payload attachment system SHALL incorporate a modular quick-release mechanism, allowing for the attachment of various payloads with minimal setup time.

##### CAN Integration:

The payload system SHALL support CAN bus integration to facilitate seamless data communication between the payload and the flight controller.

##### 12V Power Feed:

The aircraft SHALL provide a dedicated 12V power line for powering payloads, adaptable to a variety of equipment.

#####  Front-Facing Camera:

The aircraft SHALL be equipped with a fixed front-facing camera for navigation or visual feedback.

#####  Down-Facing Camera:

The aircraft SHALL include a fixed downward-facing camera for mission support and landing assistance.

#####  Video Telemetry Range:

The video telemetry SHALL have 1 km of range.

### 2.5 Flight Testing and Verification

A comprehensive testing program is required for PT1, verifying core flight performance, structural strength, electrical reliability, and payload handling capabilities. Testing should document essential parameters and establish baseline operational limits, providing valuable data to inform subsequent design iterations.

### 2.6 Regulatory Compliance

PT1, and all subsequent Quiver systems shall be built to comply with [CFR Part 107 Small Unmanned Aircraft Systems](https://www.ecfr.gov/current/title-14/chapter-I/subchapter-F/part-107) standards and requirements.

----------

# 3. Prototype Specifications

### 3.1 Flight-Critical Systems

-   Flight Controller: Utilizes a Pixhawk 6X flight management System, precision navigation, and autonomous flight modes. Must include redundancy across critical sensors (IMU, GPS, barometer).
    
-   Navigation Sensors: Include dual GNSS modules, providing high accuracy positioning with the possibility of extension to Real-Time Kinematics (RTK) support to facilitate precise waypoint navigation and payload delivery.

### 3.2 Structure and Geometry

-   Frame Material: Employ carbon fiber tubes interconnected with aluminum joints for strength-to-weight optimization. The frame configuration shall be aluminum plating able to accommodate interchangeable arm sections to simplify repairs and upgrades.
    
-   Maximum Takeoff Weight (MTOW): Prototype must support a total weight exceeding 25 kg.
    
-   Payload Capacity: Minimum payload capability of 10 kg is required to validate heavy-lift capabilities.
    
-   Structural Safety Factor: Structural integrity must ensure a safety factor of at least 2.5 times the maximum anticipated operational loads.

### 3.3 Propulsion and Power

-   Motors and ESCs: Select commercial-grade brushless DC motors rated for 12S to 14S battery configurations, paired with ESCs capable of sustaining at least 80A continuous current, ensuring sufficient thrust-to-weight performance.
    
-   Battery System: LiPo or Li-Ion battery packs rated at 12S or 14S voltage levels must guarantee a minimum of 20 minutes endurance under fully loaded conditions.
    
-   Propellers: Integrate foldable carbon-fiber propellers optimized specifically for heavy-lift efficiency, minimizing noise and maximizing flight endurance.

### 3.4 Electrical Systems

-   Electrical Layout: Wiring harnesses shall be modular and clearly labeled for ease of maintenance and fault isolation. All wiring must be heat-resistant and abrasion-resistant to withstand harsh operational environments.
    
-   Power Distribution: Install dedicated circuit switches to protect critical flight electronics and payload circuits from potential short circuits or electrical surges.

### 3.5 Payload Handling and Camera

-   Gimbal System: Implement a 3-axis stabilized gimbal, providing precise control of camera orientation to deliver steady footage even in turbulent flight conditions.
    
-   Camera Capabilities: Equip PT1 with a camera capable of delivering at least 1080p resolution at 30fps, streaming live footage directly to the ground control system with minimal latency.
    
-   Payload Attachment Interface: Establish a quick-release payload rail system with adjustable balance points, enabling secure payload attachment and easy in-field interchangeability.

### 3.6 Flight Control and Telemetry

-   Communication Systems: Employ telemetry links capable of maintaining reliable communication over distances of at least 2 km, utilizing 900 MHz or 2.4 GHz bands, backed by a redundant 433 MHz communication link as a fallback option.
    
-   Ground Control Station (GCS): Real-time telemetry data, including flight parameters, payload conditions, and battery health, must be continuously transmitted to the operator’s interface.

### 3.7 Environmental and Operational Specifications

-   Operating Temperature: The drone shall reliably operate in a temperature range from -10°C to +45°C, enabling effective use in diverse environmental conditions.
    
-   Wind and Moisture Resistance: Prototype must maintain stable flight control in wind speeds up to 25 km/h and include basic splash-resistant protection for electrical and propulsion systems, protecting against incidental moisture exposure.

### 3.8 Maintenance, Assembly, and Documentation

-   Assembly Instructions: BOMs and detailed assembly instructions should be created and provided.
    
-   Assembly Efficiency: Assembly of the UAV, including installation of payloads and batteries, shall be achievable within 60 minutes by trained personnel from packaged state.
    
-   Maintenance Schedule: A clear and concise maintenance manual detailing procedures and inspection intervals must be provided.

### 3.9 Flight Testing and Validation

-   Initial Flight Tests: Conduct controlled test flights covering hover stability, maneuverability, payload management, and endurance under realistic operational scenarios. All results and incidents should be carefully documented.
    
- Documentation: Provide comprehensive documentation, including flight logs, inspection reports, photographic and video evidence of successful testing outcomes, ensuring traceability of performance improvements for future iterations.

# 4. **Mission Performance**

Below is a mission performance analysis of maximum possible flight time for two missions: Surveillance and Waypoint Missions both under a Tattu 3.5 14S LiHV 30 Ah battery.

Key assumptions:

- **Usable Battery**: 21.6 Ah (after 2C derating to ~27 Ah, then a 20% reserve).  
- **Propulsion**: 4 Hobbywing X6 Plus motors.  
- **Mission Legs**: short, fixed‐time take‐off, climb, descent, landing; the remaining time is the main mission leg.
- **Real-World Effects**: Climb rates, aerodynamic efficiency, battery health, and environmental conditions do not affect the performance.  

## 4.1. Surveillance Mission

In this mission, the aircraft hovers with 20 kg MTOW without any payload, using its camera for surveillance.

### 4.1.1. Current Requirements

- Hover Current (20 kg): ~40.9 A (estimated from thrust‐vs‐current data of Hobbywing X6 Plus).  
- Take‐Off / Climb (110%): ~48.6 A  
- Descent (90%): ~35.5 A  
- Landing (100%): ~40.9 A

### 4.1.2. Mission Leg Times

- Take‐off: 0.5 min  
- Climb: 1.5 min  
- Descent: 1.0 min  
- Landing: 1.0 min  

Convert each to hours and multiply by current to get amp‐hours.

1. **Take‐off (0.5 min)**  
   - 0.5 min = 0.0083 hr  
   - 48.6 A × 0.0083 hr ≈ 0.40 Ah  

2. **Climb (1.5 min)**  
   - 1.5 min = 0.025 hr  
   - 48.6 A × 0.025 hr = 1.22 Ah  

3. **Descent (1.0 min)**  
   - 1.0 min = 0.0167 hr  
   - 35.5 A × 0.0167 hr ≈ 0.59 Ah  

4. **Landing (1.0 min)**  
   - 1.0 min = 0.0167 hr  
   - 40.9 A × 0.0167 hr ≈ 0.68 Ah  

Sum of non‐mission legs = **2.89 Ah**.

### 4.1.3. Maximum Hover Duration

Remaining capacity for hover = 21.6 Ah − 2.89 Ah = **18.71 Ah**.  
At 40.9 A (hover), available hover time = 18.71 Ah ÷ 40.9 A ≈ **0.457 hr** = ~27.4 min.

**Total Surveillance Flight Time**  
- Non‐mission legs: 0.5 + 1.5 + 1.0 + 1.0 = 4.0 min  
- Hover: ~27.4 min  
- **Overall**: ~31.4 min  

## 4.2. Waypoint Mission

In this mission, the aircraft travels with 25 kg MTOW between waypoints. The power consumption for forward flight is assumed as 120% of hover.

### 4.2.1. Current Requirements

- Hover Current (25 kg): ~57.5 A  
- Forward Flight (120%): ~69 A
- Take‐Off/Climb (110%): ~66.5 A  
- Descent (90%): ~49.9 A  
- Landing (100%): ~57.5 A

### 4.2.2. Mission Leg Times

- Take‐off: 1.0 min  
- Climb: 2.0 min  
- Descent: 1.0 min  
- Landing: 1.0 min  

1. **Take‐off (1.0 min)**  
   - 1.0 min = 0.0167 hr  
   - 66.5 A × 0.0167 hr ≈ 1.11 Ah  

2. **Climb (2.0 min)**  
   - 2.0 min = 0.0333 hr  
   - 66.5 A × 0.0333 hr ≈ 2.22 Ah  

3. **Descent (1.0 min)**  
   - 1.0 min = 0.0167 hr  
   - 49.9 A × 0.0167 hr ≈ 0.83 Ah  

4. **Landing (1.0 min)**  
   - 1.0 min = 0.0167 hr  
   - 57.5 A × 0.0167 hr ≈ 0.96 Ah  

Sum of these legs = **5.12 Ah**.

### 4.2.3. Maximum Forward‐Flight Duration

Remaining capacity for forward flight = 21.6 Ah − 5.12 Ah = **16.48 Ah**.  
At 69 A, flight time = 16.48 Ah ÷ 69 A ≈ **0.239 hr** = ~14.3 min.

**Total Loiter Flight Time**  
- Non‐mission legs: 1.0 + 2.0 + 1.0 + 1.0 = 5.0 min  
- Forward flight: ~14.3 min  
- **Overall**: ~19.3 min

## 4.3. Summary

Under ideal conditions, Project Quiver PT1 achieves a total flight time of approximately 31.4 minutes for surveillance missions at 20 kg MTOW, including about 27.4 minutes of hover. For waypoint missions at the full 25 kg MTOW, total flight time is around 19.3 minutes, with roughly 14.3 minutes of forward flight. Both mission scenarios incorporate a 20% battery reserve to ensure operational safety. Actual performance may vary due to environmental conditions and operational factors.

# 5. **Flight Mechanics**

This section presents the flight mechanics analysis of Project Quiver, with a focus on assessing its dynamic behavior, stability characteristics, and control performance under operational loading conditions. The aircraft has a maximum MTOW of 25 kg, and two critical configurations were evaluated:

- **No Payload Configuration (18 kg):** Vehicle equipped with propulsion system, avionics, and battery, but without any payload modules.
- **With Brush Bullet Dispenser (22 kg):** Includes a 4 kg payload module mounted at (0, 0, -40 cm) relative to the center of gravity, simulating an operational mission loadout.

A simulation environment based on MATLAB Simulink (adapted from the asbQuadcopter model) was developed to characterize the system response. The model incorporates a cascaded PID controller structure for attitude and altitude stabilization.

## 5.1 Static and Dynamic Stability Analysis

### 5.1.1 Static Stability

Static stability describes the initial tendency of the vehicle to return to equilibrium following a small disturbance.

- **Center of Gravity (CG) Effects:**  
  - In the no payload configuration, the CG is closely aligned with the vehicle’s geometric center, resulting in neutral static stability in roll and pitch.  
  - In the brush bullet dispenser configuration, the CG is shifted downward, which contributes to improved pendulum-like passive stability, but at the cost of increased rotational inertia.

- **Static Margin:**  
  - The vertical CG offset in the payload configuration increases the static margin, enhancing stability in hover but reducing control responsiveness.

### 5.1.2 Dynamic Stability

Dynamic stability pertains to the time-dependent response of the system to disturbances.

- **Eigenvalue Analysis:**  
  - Both configurations exhibit eigenvalues with negative real parts, indicating asymptotic stability.  
  - The brush bullet dispenser configuration shows reduced damping ratios and lower natural frequencies due to increased inertia, leading to longer settling times.

- **Estimated Damping Ratios (ζ):**  
  - No Payload: 0.65 – 0.8  
  - With Brush Bullet Dispenser: 0.5 – 0.6

- **Time-to-Half (τₕ):**  
  - No Payload: 0.8 – 1.2 s  
  - With Brush Bullet Dispenser: 1.4 – 1.8 s

- **Phugoid and Oscillatory Modes:**  
  - Both configurations exhibit mild phugoid-like modes due to coupling between pitch and vertical motion, with greater amplitude and period in the payload configuration.

## 5.2 Trim Analysis

Trim conditions represent the steady-state control inputs required to maintain hover.

- **Hover Thrust per Motor:**  
  - No Payload: ~4.5 kgf/motor  
  - With Brush Bullet Dispenser: ~5.5 kgf/motor

- **Trim Attitude Angles:**  
  - No Payload: < 0.5° in all axes  
  - With Brush Bullet Dispenser: Requires a forward pitch trim of approximately 0.9° due to the CG offset

- **Power Margin:**  
  - No Payload: ~45% thrust reserve  
  - With Brush Bullet Dispenser: ~30%, approaching the control authority limits under aggressive conditions

## 5.3 Control Response and Maneuverability

System responsiveness was evaluated via step response analysis and control effort metrics.

### 5.3.1 Step Response Characteristics
The actual control architecture and gains in Ardupilot were not replicated in the Simulink model, instead, a simplified cascaded PID controller was employed. These values do not represent the actual Ardupilot controller performance, rather, result of the tuned cascaded PID system.

- **Rise Time (10–90%):**  
  - No Payload: ~0.45 s  
  - With Brush Bullet Dispenser: ~0.65 s

- **Settling Time (±2%):**  
  - No Payload: ~1.2 s
  - With Brush Bullet Dispenser: ~1.8 s

- **Overshoot:**  
  - No Payload: ~5%  
  - With Brush Bullet Dispenser: ~12%

### 5.3.2 Control Effort and Authority

- **Required Control Effort in Pitch Maneuvers:**  
  - No Payload: ~15% of available motor thrust  
  - With Brush Bullet Dispenser: ~22%, increasing actuator workload

- **Motor Saturation Risk:**  
  - In the payload configuration, motor commands approach 85% of maximum thrust during aggressive inputs, reducing margin for disturbance rejection or emergency maneuvers

## 5.4 Lateral-Directional Stability

- **Cross-Axis Coupling:**  
  - Slight increase in roll-yaw coupling observed in the brush bullet dispenser configuration due to the lower CG, but remains within controllable limits.

- **Spiral Mode and Longitudinal Coupling:**  
  - No divergent spiral or unstable longitudinal modes detected in either configuration.

## 5.5 Disturbance Rejection Performance

### 5.5.1 Wind Gust Response (Lateral)

- **Simulated Wind Input:** Step disturbance of 5 m/s applied laterally  
- **Recovery Time:**  
  - No Payload: ~1.5 s  
  - With Brush Bullet Dispenser: ~3.2 s, with greater drift before correction

### 5.5.2 Vertical Gust Response

- **Simulated Vertical Gust:** ±2 m/s impulse  
- **Altitude Excursion:**  
  - No Payload: ~15 cm  
  - With Brush Bullet Dispenser: ~25 cm

## 5.6 Conclusions

- Both configurations exhibit stable dynamic behavior, but the payload configuration is slower to respond and more susceptible to disturbances due to increased mass and inertia.
- The control authority in the payload configuration is significantly reduced, and motor saturation may occur under high-demand maneuvers.
- Disturbance rejection performance is degraded in the payload configuration, requiring longer recovery times.
- Hover and trim characteristics remain within acceptable ranges, but controller gains may require re-tuning for payload missions to improve damping and responsiveness.

# 6. **Propulsion System**

Based on the Quiver project specifications, the following manufacturers for electric motors, compatible propellers, and ESCs were evaluated.

## Table 1. Drone Propulsion System Comparison for 25 kg MTOW

| Feature | System 1 | System 2 | System 3 | System 4 | System 5 | System 6 |
| --- | --- | --- | --- | --- | --- | --- |
| **Motor** | MAD 6215 IPE | T-Motor P80Ⅲ P | T-Motor P60 | MAD M6C12 EEE | Freerchobby FRC Heavy | Hobbywing XRotor X6 Plus (integrated system) |
| **Max Thrust** | 11.5 kg | 16 kg | 8.5 kg | 9.4 kg | 11.5 kg | 11.822 kg |
| **Voltage (V)** | 44.4V (12S) | 44.4V (12-14S) | 44.4V (12-14S) | 44.4V (12-14S) | 48V (6S-12S) | 44.4V (12-14S) |
| **Max Current (A)** | 60A | 70A | 38A | 36.2A | 59.7A | 51.8A |
| **Price (USD)** | $98 | $199.9 | $107.9 | $129 | $62 | $97 |
| **Weight (g)** | 370 g | 649 g | 225 g | 257 g | 370 g | 710 g (integrated) |
| **Recommended Propeller** | 21-22" | 30-32" | 22" | 21-24" | 22" | 24" |
| **Propeller Cost Estimation** | $28 | $45 | $28 | $28 | $28 | Included |
| **Propeller Weight Estimation** | 0.065 kg | 0.170 kg | 0.065 kg | 0.065 kg | 0.065 kg | Included |
| **ESC** | MAD AMPX 80A (5-14S) Drone ESC | MAD AMPX 80A (5-14S) Drone ESC | MAD AMPX 80A (5-14S) Drone ESC | MAD AMPX 80A (5-14S) Drone ESC | MAD AMPX 80A (5-14S) Drone ESC | Included |
| **ESC Cost** | $60 | $60 | $60 | $60 | $60 | Included |
| **ESC Weight** | 0.19 kg | 0.19 kg | 0.19 kg | 0.19 kg | 0.19 kg | Included |
| **System Thrust** | 46 kg | 64 kg | 34 kg | 37.6 kg | 46 kg | 47.288 kg |
| **System Weight** | 2.5 kg | 4.035 kg | 1.92 kg | 2.048 kg | 2.5 kg | 2.84 kg |
| **System Cost** | $744 | $1,219.6 | $783.6 | $868 | $600 | $388 |

The **Hobbywing XRotor X6 Plus integrated propulsion system** is selected as the best match for QUIVER propulsion requirements in terms of thrust, weight, and cost. Integrated propulsion systems combine a motor, ESC, and propeller into one optimized unit. This system offers the lowest cost compared to other evaluated options, with comparable weight. It includes power cables which can be trimmed to the necessary length. Advantages of an integrated system include optimized performance due to matched components, reduced electrical losses from shorter wiring, improved aerodynamics, and waterproof casing, significantly reducing installation workload.
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

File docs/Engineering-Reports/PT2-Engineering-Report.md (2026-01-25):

---
title: PT2 Engineering Report
sidebar_position: 2
description: Engineering report for Project Quiver Prototype 2
---

# Project Quiver PT2 Engineering Report

See also: [PT1 Engineering Report](./PT1-Engineering-Report)

---

## Introduction

The purpose of Project Quiver is to design and manufacture a practical multi-purpose multi-rotor unmanned aerial vehicle. Its purpose is to promote Arrow's decentralized organization to explore the commercial aviation service market and generate new concepts for the manufacturing process of subsequent unmanned and manned aircraft models, to explore new materials, new structures, new communication protocol and other related technologies. And try to break the current lack of innovation in the drone market around the United States and even the world by Internet collaborate and decentralized finance (DeFi).

This aircraft is designed to perform typical light UAV missions. The design concept is: compact and portable, easy to manufacture, easy to maintenance, highly reliable, highly adaptable, and expandable.

The PT2 prototype of this Project Quiver will contain the following features:
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

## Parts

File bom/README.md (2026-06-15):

# Quiver Bill of Materials — Master Data

These YAML files are the **source of truth** for what goes into a Quiver
Dev-Kit. The procurement CSV and the docs BOM page are generated from
them — never edit those by hand:

```sh
python -m quiver.bom validate   # check the data
python -m quiver.bom render     # regenerate docs/Manufacturing/BOM.md + quiver-bom.csv
```

CI rejects changes where the generated outputs are stale, and the test
suite cross-checks part IDs and quantities against the CAD assembly.

## Files

| File | Contents |
|---|---|
| `meta.yaml` | Vehicle config and dates |
| `1000-airframe-structure.yaml` | Plates, beams, landing gear, motor arms |
| `2000-supporting-structure.yaml` | Interfaces, sliders, mounts, enclosure |
| `3000-equipment.yaml` | Propulsion, sensors, PCBs, battery |
| `4000-harness.yaml` | Busbars, harness assemblies, harness supplies |
| `fasteners.yaml` | Screws, rivets, inserts, washers (`FAST-`) |
| `consumables.yaml` | Adhesives, filament (`CONS-`), tools (`TOOL-`) |

## Item schema

```yaml
- id: "1310"             # 4-digit CAD BOM id, or FAST-/CONS-/TOOL-/HAR-/HSUP- prefix
  name: Landing Gear Vertical Tube
  qty: 4                 # per vehicle; "AR" (as required) for CONS/TOOL only
  sourcing: cut-to-length  # laser-cut | 3d-print | cut-to-length | cots | pcb-assembly | harness
  material: Carbon fiber 3K     # required for make items
  finish: ...                   # optional
  spec: 30x28 mm tube           # what a shop needs to quote
  design_ref: src/quiver/...    # repo path; must exist
  production_bom: src/pcb/...   # pcb-assembly items only
  unit_cost_usd: 45.00          # indicative, per purchased unit
  purchase:                     # only when order qty differs from vehicle qty
    qty: 2
    note: 1000 mm stock yields two legs
  included_in: "3280"           # part arrives inside another item's kit
  notes: ...
```

Rules enforced by `validate`:

- IDs are unique across all files; 4-digit IDs must be quoted strings.
- 4-digit IDs must match the CAD label for modeled parts (tested in CI
  against the assembly: the BOM `qty` must cover the CAD instance count).
- `cots` items need at least one supplier with a part number or URL,
  unless `included_in` points at the item whose kit supplies them.
- Make items (`laser-cut`, `3d-print`, `cut-to-length`) should carry a
  `design_ref`; missing ones are warnings until the drawing lands.

## Versioning

Manufacturers building customer orders pin against a
[tagged GitHub release](https://github.com/Arrow-air/project-quiver/releases),
not the live BOM. When a change affects what a manufacturer buys or
builds, update `meta.yaml: date` in the PR and cut a release after
merging (attach the generated `quiver-bom.csv` to the release). Items
marked `TBC` in their notes are unconfirmed — resolve any TBCs before
cutting a release.

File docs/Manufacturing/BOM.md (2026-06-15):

---
title: Bill of Materials
sidebar_label: Bill of Materials
sidebar_position: 1
description: Quality reference BOM for the Quiver Dev-Kit
---

<!-- Generated by `python -m quiver.bom render` from bom/*.yaml. Do not edit by hand. -->

# Bill of Materials

**Dev-Kit configuration** — updated 2026-06-12

This page is generated from the version-controlled BOM master data in
[`bom/`](https://github.com/Arrow-air/project-quiver/tree/main/bom).
Manufacturers building for customer orders must build against a tagged
[GitHub release](https://github.com/Arrow-air/project-quiver/releases)
rather than this live page, which tracks the latest design.

**Download:** [procurement CSV](./quiver-bom.csv) — one row per line
item with order quantities, supplier links, and indicative costs.

Indicative build cost: **$6,590.36** (component prices as of
2026-04-14; verify with suppliers before ordering).

## Airframe Structure

| ID | Part | Qty | Sourcing | Material / Spec | Supplier | Unit cost | Design |
|---|---|---|---|---|---|---|---|
| 1111 | Upper Plate | 1 | laser-cut | Aluminum — 1 mm sheet | [RapidDirect](https://www.rapiddirect.com/) | $26.00 | [design](https://github.com/Arrow-air/project-quiver/blob/main/src/quiver/airframe_structure/plates/steps/1111_upper_plate.step) |
| 1112 | Middle Plate | 1 | laser-cut | Aluminum — 1 mm sheet | [RapidDirect](https://www.rapiddirect.com/) | $26.00 | [design](https://github.com/Arrow-air/project-quiver/blob/main/src/quiver/airframe_structure/plates/steps/1112_middle_plate.step) |
| 1113 | Lower Plate | 1 | laser-cut | Aluminum — 1 mm sheet | [RapidDirect](https://www.rapiddirect.com/) | $47.00 | [design](https://github.com/Arrow-air/project-quiver/blob/main/src/quiver/airframe_structure/plates/steps/1113_lower_plate.step) |
| 1211 | Cockpit Support Beam, CW Long | 1 | laser-cut | Aluminum — 40x40x2 mm box section | [RapidDirect](https://www.rapiddirect.com/) | $43.00 | [design](https://github.com/Arrow-air/project-quiver/blob/main/src/quiver/airframe_structure/beams/steps/1211_cw_long.step) |
| 1212 | Cockpit Support Beam, CCW Back | 2 | laser-cut | Aluminum — 40x40x2 mm box section | [RapidDirect](https://www.rapiddirect.com/) | $27.00 | [design](https://github.com/Arrow-air/project-quiver/blob/main/src/quiver/airframe_structure/beams/steps/1212_ccw_back.step) |
| 1221 | Battery Wall | 2 | laser-cut | Aluminum | [RapidDirect](https://www.rapiddirect.com/) | $49.00 | [design](https://github.com/Arrow-air/project-quiver/blob/main/src/quiver/airframe_structure/beams/steps/1221_battery_wall.step) |
| 1310 | Landing Gear Vertical Tube | 4 (order 2) | cut-to-length | Carbon fiber 3K — 30x28 mm tube; see landing_gear assembly for cut length | [RJXHobby](https://www.rjxhobby.com/carbon-fiber/carbon-fiber-tube/rjx-1pcs-colored-3k-carbon-fiber-tube-1000mm-od-21-30mm) | $45.00 | [design](https://github.com/Arrow-air/project-quiver/blob/main/src/quiver/airframe_structure/landing_gear/assembly.py) |
| 1320 | Landing Gear Horizontal Tube | 2 (order 1) | cut-to-length | Carbon fiber 3K — 30x28 mm tube; see landing_gear assembly for cut length | [RJXHobby](https://www.rjxhobby.com/carbon-fiber/carbon-fiber-tube/rjx-1pcs-colored-3k-carbon-fiber-tube-1000mm-od-21-30mm) | $45.00 | [design](https://github.com/Arrow-air/project-quiver/blob/main/src/quiver/airframe_structure/landing_gear/assembly.py) |
| 1330 | Landing Gear Main Adapter | 4 | cots | 30 mm tube quick-release tilt seat | [RJXHobby](https://www.rjxhobby.com/rjx-1pcs-20mm-quick-release-tripod-aluminum-tilt-fixed-seat-landing-gear-connector-1) | $30.00 | [design](https://github.com/Arrow-air/project-quiver/blob/main/src/quiver/airframe_structure/landing_gear/steps/vendor/1330_main_adapter.step) |
| 1340 | Landing Gear Tube Joint | 4 | cots | 30 mm | [INNLOI](https://www.innloi.com/productinfo/448455.html) | $13.99 | [design](https://github.com/Arrow-air/project-quiver/blob/main/src/quiver/airframe_structure/landing_gear/steps/1340_tube_joint.step) |
| 1350 | Landing Gear Foam Wrap | 4 (order 1) | cots | EPP foam | [Amazon](https://a.co/d/ggzWXc4) | $14.00 | [design](https://github.com/Arrow-air/project-quiver/blob/main/src/quiver/airframe_structure/landing_gear/assembly.py) |
| 1411 | Foldable Motor Arm Connector | 4 | cots | 30 mm tube option | [Alibaba](https://www.alibaba.com/product-detail/30-40mm-Folding-arm-tube-Drone_1600762096177.html) | $25.00 | [design](https://github.com/Arrow-air/project-quiver/blob/main/src/quiver/airframe_structure/motor_arm/steps/vendor/1411_arm_connector.step) |
| 1412 | Motor Arm Tube | 4 (order 2) | cut-to-length | Carbon fiber 3K — 30x28 mm tube, cut to 360 mm | [RJXHobby](https://www.rjxhobby.com/carbon-fiber/carbon-fiber-tube/rjx-1pcs-colored-3k-carbon-fiber-tube-1000mm-od-21-30mm) | $45.00 | [design](https://github.com/Arrow-air/project-quiver/blob/main/src/quiver/airframe_structure/motor_arm/assembly.py) |

## Supporting Structure

| ID | Part | Qty | Sourcing | Material / Spec | Supplier | Unit cost | Design |
|---|---|---|---|---|---|---|---|
| 2111 | Attachment Interface Spacer, Left/Right | 2 | 3d-print | PETG-CF |  |  | [design](https://github.com/Arrow-air/project-quiver/blob/main/src/quiver/supporting_structure/attachment_interface/steps/2111_attach_spacer.step) |
| 2112 | Quick-Release Interface Plate | 3 | cots | Aluminum | [Alibaba](https://www.alibaba.com/product-detail/Quick-Release-Clip-Plate-Clamp-Quick_1600982145247.html) | $34.00 | [design](https://github.com/Arrow-air/project-quiver/blob/main/src/quiver/supporting_structure/attachment_interface/steps/2112_attach_plate.step) |
| 2131 | Attachment Interface Spacer, Bottom | 1 | 3d-print | PETG-CF |  |  | [design](https://github.com/Arrow-air/project-quiver/blob/main/src/quiver/supporting_structure/attachment_interface/steps/2131_attach_spacer_bottom.step) |
| 2211 | Battery Slider | 2 | 3d-print | PETG-CF |  |  | [design](https://github.com/Arrow-air/project-quiver/blob/main/src/quiver/supporting_structure/battery_slider/steps/2211_battery_slider.step) |
| 2311 | Main PCB Mount | 1 | 3d-print | PETG-CF |  |  | [design](https://github.com/Arrow-air/project-quiver/blob/main/src/quiver/supporting_structure/equipment_mount/steps/2311_main_pcb_mount.step) |
| 2312 | BC PCB Mount | 1 | 3d-print | PETG-CF |  |  | [design](https://github.com/Arrow-air/project-quiver/blob/main/src/quiver/supporting_structure/equipment_mount/steps/2312_bc_pcb_mount.step) |
| 2313 | BC PCB Cover | 1 | 3d-print | PETG-CF |  |  | [design](https://github.com/Arrow-air/project-quiver/blob/main/src/quiver/supporting_structure/equipment_mount/steps/2313_bc_pcb_cover.step) |
| 2321 | Altitude Sensor Mount | 1 | 3d-print | PETG-CF |  |  | [design](https://github.com/Arrow-air/project-quiver/blob/main/src/quiver/supporting_structure/equipment_mount/steps/2321_altitude_sensor_mount.step) |
| 2331 | GNSS Mount Base | 1 | 3d-print | PETG-CF |  |  | [design](https://github.com/Arrow-air/project-quiver/blob/main/src/quiver/supporting_structure/equipment_mount/steps/2331_gnss_mount_base.step) |
| 2332 | GNSS Mount Clamp | 1 | 3d-print | PETG-CF |  |  | [design](https://github.com/Arrow-air/project-quiver/blob/main/src/quiver/supporting_structure/equipment_mount/steps/2332_gnss_mount_clamp.step) |
| 2341 | PPP Adapter and Beacon Mount | 1 | 3d-print | PETG-CF |  |  | [design](https://github.com/Arrow-air/project-quiver/blob/main/src/quiver/supporting_structure/equipment_mount/steps/2341_ppp_beacon_mount.step) |
| 2411 | Main Enclosure | 1 | 3d-print | PETG-CF |  |  | [design](https://github.com/Arrow-air/project-quiver/blob/main/src/quiver/supporting_structure/cockpit_enclosure/steps/2411_main_enclosure.step) |
| 2412 | Enclosure Top Cap | 1 | 3d-print | PETG-CF |  |  | [design](https://github.com/Arrow-air/project-quiver/blob/main/src/quiver/supporting_structure/cockpit_enclosure/steps/2412_enclosure_top_cap.step) |
| 2420 | Enclosure Hinge | 2 | cots | Zinc die-cast | [JW Winco GN 237-ZD-30-30-A-SW](https://www.jwwinco.com/en-us/products/3.3-Hinging-latching-locking-of-doors-and-covers/Hinges/GN-237-Zinc-Die-Cast-or-Aluminum-Hinges-Countersunk-Thru-Holes-or-Thre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) | $10.00 | [design](https://github.com/Arrow-air/project-quiver/blob/main/src/quiver/supporting_structure/cockpit_enclosure/steps/2420_hinge.step) |
| 2430 | Enclosure Latch | 2 | cots | Steel | [McMaster-Carr 6082A11](https://www.mcmaster.com/6082A11/) | $10.42 | [design](https://github.com/Arrow-air/project-quiver/blob/main/src/quiver/supporting_structure/cockpit_enclosure/steps/2430_latch.step) |

## Equipment

| ID | Part | Qty | Sourcing | Material / Spec | Supplier | Unit cost | Design |
|---|---|---|---|---|---|---|---|
| 3111 | Motor + ESC, Hobbywing XRotor X6 Plus | 4 | cots |  | [Hobbywing XRotor X6 Plus G2](https://www.hobbywing.com/en/products/x6-plus-g2) | $120.00 | [design](https://github.com/Arrow-air/project-quiver/blob/main/src/quiver/equipment/propulsion/steps/vendor/3111_motor.step) |
| 3112 | Propeller, Hobbywing MFP 24x8.0, CW | 2 | cots |  | [Hobbywing MFP 24x8.0 CW](https://www.hobbywing.com/en/products/mfp-24x80) | $20.00 | [design](https://github.com/Arrow-air/project-quiver/blob/main/src/quiver/equipment/propulsion/steps/vendor/3112_propeller.step) |
| 3122 | Propeller, Hobbywing MFP 24x8.0, CCW | 2 | cots |  | [Hobbywing MFP 24x8.0 CCW](https://www.hobbywing.com/en/products/mfp-24x80) | $20.00 | [design](https://github.com/Arrow-air/project-quiver/blob/main/src/quiver/equipment/propulsion/steps/vendor/3122_propeller.step) |
| 3201 | PPP Adapter, CubePilot CubeNode ETH | 1 | cots |  | [IR-LOCK (CubePilot)](https://irlock.com/products/cube-node-eth?variant=42727353122867) | $121.98 | [design](https://github.com/Arrow-air/project-quiver/blob/main/src/quiver/equipment/peripheral/steps/vendor/3201_ppp_adapter.step) |
| 3202 | Remote ID Module, DroneBeacon db201 | 1 | cots |  | [DroneScout (DroneBeacon) db201](https://dronescout.co/product/dronebeacon-mavlink-db201-transponder/) | $54.00 | [design](https://github.com/Arrow-air/project-quiver/blob/main/src/quiver/equipment/peripheral/steps/vendor/3202_drone_beacon.step) |
| 3210 | Obstacle Avoidance LiDAR, RPLidar S2L | 1 | cots |  | [DFRobot](https://www.dfrobot.com/product-2617.html) | $380.00 | [design](https://github.com/Arrow-air/project-quiver/blob/main/src/quiver/equipment/peripheral/steps/vendor/3210_oa_lidar.step) |
| 3220 | Radar Altimeter, Nanoradar NRA15 | 1 | cots |  | [Nanoradar NRA15](https://www.nanoradar.com/Products_1/4.html) | $240.00 | [design](https://github.com/Arrow-air/project-quiver/blob/main/src/quiver/equipment/peripheral/steps/vendor/3220_radar_altimeter.step) |
| 3230 | Telemetry Antenna, Front | 1 | cots |  | included with 3280 |  | [design](https://github.com/Arrow-air/project-quiver/blob/main/src/quiver/equipment/peripheral/steps/vendor/3230_front_telemetry.step) |
| 3240 | Telemetry Antenna, Rear | 1 | cots |  | included with 3280 |  | [design](https://github.com/Arrow-air/project-quiver/blob/main/src/quiver/equipment/peripheral/steps/vendor/3240_rear_telemetry.step) |
| 3250 | GNSS Module, Primary | 1 | cots |  | [IR-LOCK (CubePilot) Here4](https://irlock.com/products/here4-multiband-rtk-gnss); [Holybro H-RTK F9P (DroneCAN)](https://holybro.com/) | $288.00 | [design](https://github.com/Arrow-air/project-quiver/blob/main/src/quiver/equipment/peripheral/steps/vendor/3250_gnss_wren_mini.step) |
| 3251 | GNSS Module, Backup, Mateksys M9N-G4-3100 | 1 | cots |  | [Mateksys M9N-G4-3100](https://www.mateksys.com/?portfolio=m9n-g4-3100) | $125.00 |  |
| 3260 | Power Switch, E-Switch PVHC4F23SS344 | 1 | cots |  | [Digi-Key PVHC4F23SS344](https://www.digikey.com/en/products/detail/e-switch/PVHC4F23SS344/24614861) | $16.00 | [design](https://github.com/Arrow-air/project-quiver/blob/main/src/quiver/equipment/peripheral/steps/vendor/3260_power_switch.step) |
| 3270 | Gimbal Camera, SIYI A8 mini | 1 | cots |  | [SIYI](https://shop.siyi.biz/products/siyi-a8-mini-gimbal-camera) | $251.63 | [design](https://github.com/Arrow-air/project-quiver/blob/main/src/quiver/equipment/peripheral/steps/vendor/3270_camera.step) |
| 3280 | Telemetry / FPV System, SIYI HM30 | 1 | cots |  | [SIYI HM30 Standard Combo](https://shop.siyi.biz/products/siyi-hm30-digital-image-transmission?VariantsId=10748) | $282.04 | [design](https://github.com/Arrow-air/project-quiver/blob/main/src/quiver/equipment/peripheral/steps/vendor/3280_telemetry.step) |
| 3290 | Obstacle Avoidance Radar, Nanoradar MR82 | 1 | cots |  | [Nanoradar MR82](https://www.nanoradar.com/Products_1/7.html) | $285.00 | [design](https://github.com/Arrow-air/project-quiver/blob/main/src/quiver/equipment/peripheral/steps/vendor/3290_oa_radar.step) |
| 3310 | Main PCB, assembled | 1 | pcb-assembly |  |  | $400.00 | [design](https://github.com/Arrow-air/project-quiver/blob/main/src/pcb/main_pcb/) |
| 3312 | Companion Computer, Raspberry Pi 5 | 1 | cots | 8 GB RAM | [Raspberry Pi](https://www.raspberrypi.com/products/raspberry-pi-5/) | $200.00 |  |
| 3313 | Ethernet Switch, BotBlox GigaBlox Nano | 2 | cots |  | [BotBlox](https://botblox.io/products/micro-gigabit-ethernet-switch) | $95.67 |  |
| 3320 | Battery Connector PCB, assembled | 1 | pcb-assembly |  |  | $83.00 | [design](https://github.com/Arrow-air/project-quiver/blob/main/src/pcb/battery_pcb/) |
| 3324 | BC PCB Heatsink, 5 mm | 1 | laser-cut | Aluminum — 5 mm plate, 116 x 16 mm; the 5 mm variant supersedes the earlier 4 mm one | [RapidDirect](https://www.rapiddirect.com/) | $16.00 | [design](https://github.com/Arrow-air/project-quiver/blob/main/src/manufacturing/3324_bc_pcb_heatsink.step) |
| 3330 | Flight Controller PCB, assembled | 1 | pcb-assembly |  |  | $25.00 | [design](https://github.com/Arrow-air/project-quiver/blob/main/src/pcb/fc_pcb/) |
| 3331 | Attachment Interface PCB, assembled | 3 (order 6) | pcb-assembly |  |  | $10.00 | [design](https://github.com/Arrow-air/project-quiver/blob/main/src/pcb/attach_pcb/) |
| 3332 | Flight Controller, Holybro Pix32 v6 | 1 | cots |  | [Holybro](https://holybro.com/products/pix32-v6?variant=43020083527869) | $296.00 |  |
| 3410 | Battery, Tattu 4.0 14S 30000 mAh | 1 | cots |  | Tattu Tattu 4.0 14S 30000 mAh | $735.00 | [design](https://github.com/Arrow-air/project-quiver/blob/main/src/quiver/equipment/battery/steps/vendor/3410_battery.step) |
| 3501 | Remote Control Transmitter | 1 | cots |  | [RadioMaster Boxer](https://www.radiomasterrc.com/products/boxer-radio-controller-m2) | $150.00 |  |
| 3510 | Transport Case, Nanuk 976 | 1 | cots |  | [Nanuk 976](https://nanuk.com/products/nanuk-976) | $600.00 |  |

## Harness

| ID | Part | Qty | Sourcing | Material / Spec | Supplier | Unit cost | Design |
|---|---|---|---|---|---|---|---|
| 4010 | Busbar Pair, Positive + Negative | 2 | laser-cut | Copper | [RapidDirect](https://www.rapiddirect.com/) | $30.74 | [design](https://github.com/Arrow-air/project-quiver/blob/main/src/quiver/harness/steps/) |
| HAR-0001 | Harness, Pushbutton | 1 | harness |  |  |  | [design](https://github.com/Arrow-air/project-quiver/blob/main/docs/Manufacturing/Harness-Manufacturing-Guide.mdx) |
| HAR-0002 | Harness, BC PCB Signal | 1 | harness |  |  |  | [design](https://github.com/Arrow-air/project-quiver/blob/main/docs/Manufacturing/Harness-Manufacturing-Guide.mdx) |
| HAR-0003 | Harness, BC PCB SSR | 1 | harness |  |  |  | [design](https://github.com/Arrow-air/project-quiver/blob/main/docs/Manufacturing/Harness-Manufacturing-Guide.mdx) |
| HAR-0004 | Harness, ESC Power FR | 1 | harness |  |  |  | [design](https://github.com/Arrow-air/project-quiver/blob/main/docs/Manufacturing/Harness-Manufacturing-Guide.mdx) |
| HAR-0005 | Harness, ESC Power FL | 1 | harness |  |  |  | [design](https://github.com/Arrow-air/project-quiver/blob/main/docs/Manufacturing/Harness-Manufacturing-Guide.mdx) |
| HAR-0006 | Harness, ESC Power BR | 1 | harness |  |  |  | [design](https://github.com/Arrow-air/project-quiver/blob/main/docs/Manufacturing/Harness-Manufacturing-Guide.mdx) |
| HAR-0007 | Harness, ESC Power BL | 1 | harness |  |  |  | [design](https://github.com/Arrow-air/project-quiver/blob/main/docs/Manufacturing/Harness-Manufacturing-Guide.mdx) |
| HAR-0008 | Harness, ESC Signal FR | 1 | harness |  |  |  | [design](https://github.com/Arrow-air/project-quiver/blob/main/docs/Manufacturing/Harness-Manufacturing-Guide.mdx) |
| HAR-0009 | Harness, ESC Signal FL | 1 | harness |  |  |  | [design](https://github.com/Arrow-air/project-quiver/blob/main/docs/Manufacturing/Harness-Manufacturing-Guide.mdx) |
| HAR-0010 | Harness, ESC Signal BR | 1 | harness |  |  |  | [design](https://github.com/Arrow-air/project-quiver/blob/main/docs/Manufacturing/Harness-Manufacturing-Guide.mdx) |
| HAR-0011 | Harness, ESC Signal BL | 1 | harness |  |  |  | [design](https://github.com/Arrow-air/project-quiver/blob/main/docs/Manufacturing/Harness-Manufacturing-Guide.mdx) |
| HAR-0012 | Harness, Side Payload Right | 1 | harness |  |  |  | [design](https://github.com/Arrow-air/project-quiver/blob/main/docs/Manufacturing/Harness-Manufacturing-Guide.mdx) |
| HAR-0013 | Harness, Side Payload Left | 1 | harness |  |  |  | [design](https://github.com/Arrow-air/project-quiver/blob/main/docs/Manufacturing/Harness-Manufacturing-Guide.mdx) |
| HAR-0014 | Harness, Bottom Payload | 1 | harness |  |  |  | [design](https://github.com/Arrow-air/project-quiver/blob/main/docs/Manufacturing/Harness-Manufacturing-Guide.mdx) |
| HAR-0015 | Harness, Altimeter | 1 | harness |  |  |  | [design](https://github.com/Arrow-air/project-quiver/blob/main/docs/Manufacturing/Harness-Manufacturing-Guide.mdx) |
| HAR-0016 | Harness, 360 LiDAR | 1 | harness |  |  |  | [design](https://github.com/Arrow-air/project-quiver/blob/main/docs/Manufacturing/Harness-Manufacturing-Guide.mdx) |
| HAR-0017 | Harness, Front Radar | 1 | harness |  |  |  | [design](https://github.com/Arrow-air/project-quiver/blob/main/docs/Manufacturing/Harness-Manufacturing-Guide.mdx) |
| HAR-0018 | Harness, HM30 Power | 1 | harness |  |  |  | [design](https://github.com/Arrow-air/project-quiver/blob/main/docs/Manufacturing/Harness-Manufacturing-Guide.mdx) |
| HAR-0019 | Harness, HM30 Signal A | 1 | harness |  |  |  | [design](https://github.com/Arrow-air/project-quiver/blob/main/docs/Manufacturing/Harness-Manufacturing-Guide.mdx) |
| HAR-0020 | Harness, HM30 Signal B | 1 | harness |  |  |  | [design](https://github.com/Arrow-air/project-quiver/blob/main/docs/Manufacturing/Harness-Manufacturing-Guide.mdx) |
| HAR-0021 | Harness, Navigation Primary GNSS | 1 | harness |  |  |  | [design](https://github.com/Arrow-air/project-quiver/blob/main/docs/Manufacturing/Harness-Manufacturing-Guide.mdx) |
| HAR-0022 | Harness, Navigation Backup GNSS | 1 | harness |  |  |  | [design](https://github.com/Arrow-air/project-quiver/blob/main/docs/Manufacturing/Harness-Manufacturing-Guide.mdx) |
| HAR-0023 | Harness, PPP2ETH A | 1 | harness |  |  |  | [design](https://github.com/Arrow-air/project-quiver/blob/main/docs/Manufacturing/Harness-Manufacturing-Guide.mdx) |
| HAR-0024 | Harness, PPP2ETH B | 1 | harness |  |  |  | [design](https://github.com/Arrow-air/project-quiver/blob/main/docs/Manufacturing/Harness-Manufacturing-Guide.mdx) |
| HAR-0025 | Harness, PPP2ETH C | 1 | harness |  |  |  | [design](https://github.com/Arrow-air/project-quiver/blob/main/docs/Manufacturing/Harness-Manufacturing-Guide.mdx) |
| HAR-0026 | Harness, Remote ID | 1 | harness |  |  |  | [design](https://github.com/Arrow-air/project-quiver/blob/main/docs/Manufacturing/Harness-Manufacturing-Guide.mdx) |
| HAR-0027 | Harness, SIYI Camera | 1 | harness |  |  |  | [design](https://github.com/Arrow-air/project-quiver/blob/main/docs/Manufacturing/Harness-Manufacturing-Guide.mdx) |
| HAR-0028 | Harness, Antenna | 1 | harness |  |  |  | [design](https://github.com/Arrow-air/project-quiver/blob/main/docs/Manufacturing/Harness-Manufacturing-Guide.mdx) |
| HSUP-001 | XT30 Male Connector, Amass XT30U-M | 1 | cots |  | [TME XT30U-M](https://www.tme.com/us/en-us/details/xt30u-m/dc-power-connectors/amass/) | $0.83 |  |
| HSUP-002 | XT60 Male Connector, Amass XT60U-M | 4 | cots |  | [TME XT60U-M](https://www.tme.com/us/en-us/details/xt60u-m/dc-power-connectors/amass/) | $0.70 |  |
| HSUP-003 | Pluggable Terminal Block, Phoenix PTSM 0,5/2-P-2,5 WH | 1 | cots |  | [Mouser 1704853](https://mou.sr/3TUNxPr) |  |  |
| HSUP-004 | Pluggable Terminal Block, Phoenix PTSM 0,5/4-P-2,5 WH | 18 | cots |  | [Mouser 1704857](https://mou.sr/4bSpp8f) |  |  |
| HSUP-005 | Pluggable Terminal Block, Phoenix PTSM 0,5/5-P-2,5 WH | 5 | cots |  | [Mouser 1704858](https://mou.sr/4nxik2l) |  |  |
| HSUP-006 | Pluggable Terminal Block, Phoenix PTSM 0,5/6-P-2,5 WH | 5 | cots |  | [Mouser 1704859](https://mou.sr/44ach9V) |  |  |
| HSUP-007 | Hook-Up Wire Kit, 26 AWG PTFE, 10 colors | 1 | cots | 15 feet per color | [Remington Industries](https://www.remingtonindustries.com/hook-up-wire/custom-hook-up-wire-26-awg-ptfe-stranded-kit-2-spool-sizes-available-choose-10-colors/) |  |  |
| HSUP-008 | Molex 12-Pin Connector, 207760-1281 | 6 | cots |  | [Mouser 207760-1281](https://www.mouser.com/ProductDetail/Molex/207760-1281) | $1.51 |  |
| HSUP-009 | Molex MLP Receptacle Housing, 204523-1201, 12 circuits | 6 | cots |  | [Mouser 204523-1201](https://www.mouser.com/ProductDetail/Molex/204523-1201) | $0.42 |  |
| HSUP-010 | Spring-Loaded Connector, Mill-Max 813-22-010-30-000101 | 6 | cots |  | [Mouser 813-22-010-30-000101](https://www.mouser.com/ProductDetail/Mill-Max/813-22-010-30-000101) | $8.60 |  |
| HSUP-011 | SLC Target Connector, Mill-Max 419-10-210-30-054000 | 6 | cots |  | [Mouser 419-10-210-30-054000](https://www.mouser.com/ProductDetail/Mill-Max/419-10-210-30-054000) | $3.63 |  |
| HSUP-012 | Attachment Interface Cable, Molex 79758-1149 | 50 | cots |  | [Mouser 79758-1149](https://www.mouser.com/ProductDetail/Molex/79758-1149) | $1.29 |  |
| HSUP-013 | JST GH Pre-Made Cable Assortment | 1 | cots | kit covering positions 3, 4, 5, 6, 9 | [Amazon](https://www.amazon.com/dp/B07PBHN7TM) |  |  |

## Fasteners

| ID | Part | Qty | Sourcing | Material / Spec | Supplier | Unit cost | Design |
|---|---|---|---|---|---|---|---|
| FAST-001 | Rivet, 4 mm, for 1-2.5 mm grip | 26 | cots |  | [McMaster-Carr 97525A224](https://www.mcmaster.com/97525A224/) |  |  |
| FAST-002 | Rivet, 4 mm, for 2.5-4.5 mm grip | 10 | cots |  | [McMaster-Carr 97525A251](https://www.mcmaster.com/97525A251) |  |  |
| FAST-003 | Rivet, 4 mm, for 4.5-6.4 mm grip | 10 | cots |  | [McMaster-Carr 97525A226](https://www.mcmaster.com/97525A226) |  |  |
| FAST-004 | Socket Head Screw M3x10 | 8 | cots |  | [McMaster-Carr 91292A113](https://www.mcmaster.com/91292A113) |  |  |
| FAST-005 | Flanged Button Head Screw M4x10 | 16 | cots |  | [McMaster-Carr 92095A190](https://www.mcmaster.com/92095A190) |  |  |
| FAST-006 | Button Head Hex-Drive Screw M2x4 | 12 | cots |  | [McMaster-Carr 92095A451](https://www.mcmaster.com/92095A451/) |  |  |
| FAST-007 | Socket Head Screw M3x12 | 8 | cots |  | [McMaster-Carr 91292A114](https://www.mcmaster.com/91292A114) |  |  |
| FAST-008 | Socket Head Screw M3x8 | 79 | cots |  | [McMaster-Carr 91292A112](https://www.mcmaster.com/91292A112) |  |  |
| FAST-009 | Socket Head Screw M3x40 | 16 | cots |  | [McMaster-Carr 91292A024](https://www.mcmaster.com/91292A024) |  |  |
| FAST-010 | Socket Head Screw M2.5x6 | 4 | cots |  | [McMaster-Carr 91292A010](https://www.mcmaster.com/91292A010/) |  |  |
| FAST-011 | Hex Drive Flat Head Screw M3x10 | 8 | cots |  | [McMaster-Carr 92125A130](https://www.mcmaster.com/92125A130/) |  |  |
| FAST-012 | Socket Head Screw M4x8 | 8 | cots |  | [McMaster-Carr 91292A108](https://www.mcmaster.com/91292A108) |  |  |
| FAST-013 | Socket Head Screw M2x6 | 4 | cots |  | [McMaster-Carr 91292A832](https://www.mcmaster.com/91292A832/) |  |  |
| FAST-014 | Flanged Button Head Hex-Drive Screw M3x6 | 23 | cots |  | [McMaster-Carr 97654A674](https://www.mcmaster.com/products/97654a674/) |  |  |
| FAST-015 | Socket Head Hex-Drive Screw M2x5 | 4 | cots |  | [McMaster-Carr 92855A837](https://www.mcmaster.com/92855A837/) |  |  |
| FAST-016 | Socket Head Hex-Drive Screw M2.5x8 | 4 | cots |  | [McMaster-Carr 91292A012](https://www.mcmaster.com/91292A012/) |  |  |
| FAST-017 | Socket Head Hex-Drive Screw M2x10 | 4 | cots |  | [McMaster-Carr 91292A833](https://www.mcmaster.com/91292A833/) |  |  |
| FAST-018 | Socket Head Hex-Drive Screw M5x8 | 4 | cots |  | [McMaster-Carr 91292A191](https://www.mcmaster.com/91292A191) |  |  |
| FAST-019 | Button Head Hex Drive Screw M3x40 | 4 | cots |  | [McMaster-Carr 92095A203](https://www.mcmaster.com/92095A203/) |  |  |
| FAST-020 | Socket Head Screw M3x6 | 8 | cots |  | [McMaster-Carr 90751A110](https://www.mcmaster.com/90751A110/) |  |  |
| FAST-021 | Threaded Insert M3, 5.7 mm | 50 | cots |  | [McMaster-Carr 94459A140](https://www.mcmaster.com/94459A140/) |  |  |
| FAST-022 | Threaded Insert M4 | 8 | cots |  | [McMaster-Carr 94180A351](https://www.mcmaster.com/94180A351/) |  |  |
| FAST-023 | Threaded Insert M2 | 4 | cots |  | [McMaster-Carr 94180A312](https://www.mcmaster.com/94180A312/) |  |  |
| FAST-024 | Threaded Insert M3, 3.8 mm | 16 | cots |  | [McMaster-Carr 94180A331](https://www.mcmaster.com/94180A331) |  |  |
| FAST-025 | Threaded Insert M2.5 | 4 | cots |  | [McMaster-Carr 94459A439](https://www.mcmaster.com/94459A439/) |  |  |
| FAST-026 | Washer M3, General Purpose, 3.2 mm ID, 6 mm OD | 115 | cots |  | [McMaster-Carr 98689A112](https://www.mcmaster.com/98689A112) |  |  |
| FAST-027 | Washer M4, General Purpose, 4.3 mm ID, 9 mm OD | 8 | cots |  | [McMaster-Carr 93475A230](https://www.mcmaster.com/93475A230) |  |  |
| FAST-028 | Washer M2, Nylon, 2.2 mm ID, 5 mm OD | 12 | cots |  | [McMaster-Carr 95610A110](https://www.mcmaster.com/95610A110) |  |  |
| FAST-029 | Washer M2.5, Nylon, 2.7 mm ID, 5.6 mm OD | 8 | cots |  | [McMaster-Carr 95610A011](https://www.mcmaster.com/95610A011/) |  |  |
| FAST-030 | Washer M3, Nylon, 3.2 mm ID, 6 mm OD | 4 | cots |  | [McMaster-Carr 95610A704](https://www.mcmaster.com/95610A704) |  |  |
| FAST-031 | Washer M5, General Purpose, 5.3 mm ID, 10 mm OD | 4 | cots |  | [McMaster-Carr 93475A240](https://www.mcmaster.com/93475A240) |  |  |
| FAST-032 | Nylon-Insert Locknut M3 | 12 | cots |  | [McMaster-Carr 90576A811](https://www.mcmaster.com/90576A811) |  |  |
| FAST-033 | Vibration Mount, M3 Rubber Anti-Vibration Spacer | 5 | cots |  | Amazon |  |  |
| FAST-034 | Grommet, Circular, 20 mm OD | 4 | cots |  | Amazon |  |  |
| FAST-035 | Grommet, Oval, 27x13 mm | 12 | cots |  | Amazon |  |  |
| FAST-036 | Silicone Foam Seal Strip, Circular, 8 mm OD | 1 | cots |  | Amazon |  |  |

## Consumables and Tools

| ID | Part | Qty | Sourcing | Material / Spec | Supplier | Unit cost | Design |
|---|---|---|---|---|---|---|---|
| CONS-001 | Loctite Threadlocker Purple 222 | AR | cots | low-strength threadlocker | [McMaster-Carr 1810A28](https://www.mcmaster.com/1810A28) |  |  |
| CONS-002 | Loctite Threadlocker Blue 242 | AR | cots | medium-strength threadlocker | [McMaster-Carr 91458A113](https://www.mcmaster.com/91458A113) |  |  |
| CONS-003 | Loctite Threadlocker Red 262 | AR | cots | high-strength threadlocker | [McMaster-Carr 91458A170](https://www.mcmaster.com/91458A170) |  |  |
| CONS-004 | Würth Super RTV Silicone, Black | AR | cots | 200 ml | Würth 08933311 |  |  |
| CONS-005 | Double-Sided Tape, Heavy Duty | AR | cots |  | Amazon |  |  |
| CONS-006 | Bambulab PETG-CF Filament | AR (order 2) | cots |  | [Bambulab](https://us.store.bambulab.com/) | $32.00 |  |
| CONS-007 | Thermal Paste, Arctic MX-4, 20 g | AR | cots |  | [Amazon](https://a.co/d/bZ7soGb) | $12.00 |  |
| TOOL-001 | Allen Key Set, Metric M2-M5 | AR | cots |  |  |  |  |
| TOOL-002 | Wrench Set, Metric | AR | cots |  |  |  |  |
| TOOL-003 | Cordless Screwdriver or Drill Press | AR | cots |  |  |  |  |
| TOOL-004 | Riveting Tool, for 4 mm rivets | AR | cots |  |  |  |  |

## Notes

- Quantities are per vehicle; "order" quantities reflect stock sizes
  or batch minimums (full detail in the CSV).
- `AR` = as required (consumables and tools).
- PCB component-level BOMs are KiCad production exports under
  [`src/pcb/`](https://github.com/Arrow-air/project-quiver/tree/main/src/pcb)
  — each board appears here as a single assembled item.
- Items whose notes say `TBC` are unconfirmed; see
  [`bom/README.md`](https://github.com/Arrow-air/project-quiver/blob/main/bom/README.md)
  for the versioning policy.

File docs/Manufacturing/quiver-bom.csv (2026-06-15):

id | name | category | qty_vehicle | qty_order | sourcing | material | spec | supplier | supplier_part_number | supplier_url | unit_cost_usd | order_cost_usd | order_details | notes
1111 | Upper Plate | Airframe Structure | 1 | 1 | laser-cut | Aluminum | 1 mm sheet | RapidDirect |  | https://www.rapiddirect.com/ | 26.00 | 26.00
1112 | Middle Plate | Airframe Structure | 1 | 1 | laser-cut | Aluminum | 1 mm sheet | RapidDirect |  | https://www.rapiddirect.com/ | 26.00 | 26.00
1113 | Lower Plate | Airframe Structure | 1 | 1 | laser-cut | Aluminum | 1 mm sheet | RapidDirect |  | https://www.rapiddirect.com/ | 47.00 | 47.00
1211 | Cockpit Support Beam, CW Long | Airframe Structure | 1 | 1 | laser-cut | Aluminum | 40x40x2 mm box section | RapidDirect |  | https://www.rapiddirect.com/ | 43.00 | 43.00
1212 | Cockpit Support Beam, CCW Back | Airframe Structure | 2 | 2 | laser-cut | Aluminum | 40x40x2 mm box section | RapidDirect |  | https://www.rapiddirect.com/ | 27.00 | 54.00
1221 | Battery Wall | Airframe Structure | 2 | 2 | laser-cut | Aluminum |  | RapidDirect |  | https://www.rapiddirect.com/ | 49.00 | 98.00
1310 | Landing Gear Vertical Tube | Airframe Structure | 4 | 2 | cut-to-length | Carbon fiber 3K | 30x28 mm tube; see landing_gear assembly for cut length | RJXHobby |  | https://www.rjxhobby.com/carbon-fiber/carbon-fiber-tube/rjx-1pcs-colored-3k-carbon-fiber-tube-1000mm-od-21-30mm | 45.00 | 90.00 | 30x28x1000 mm stock, any color; each tube yields two legs
1320 | Landing Gear Horizontal Tube | Airframe Structure | 2 | 1 | cut-to-length | Carbon fiber 3K | 30x28 mm tube; see landing_gear assembly for cut length | RJXHobby |  | https://www.rjxhobby.com/carbon-fiber/carbon-fiber-tube/rjx-1pcs-colored-3k-carbon-fiber-tube-1000mm-od-21-30mm | 45.00 | 45.00 | 30x28x1000 mm stock, any color; one tube yields both skids
1330 | Landing Gear Main Adapter | Airframe Structure | 4 | 4 | cots |  | 30 mm tube quick-release tilt seat | RJXHobby |  | https://www.rjxhobby.com/rjx-1pcs-20mm-quick-release-tripod-aluminum-tilt-fixed-seat-landing-gear-connector-1 | 30.00 | 120.00
1340 | Landing Gear Tube Joint | Airframe Structure | 4 | 4 | cots |  | 30 mm | INNLOI |  | https://www.innloi.com/productinfo/448455.html | 13.99 | 55.96
1350 | Landing Gear Foam Wrap | Airframe Structure | 4 | 1 | cots | EPP foam |  | Amazon |  | https://a.co/d/ggzWXc4 | 14.00 | 14.00 | one pack wraps all four lower tubes
1411 | Foldable Motor Arm Connector | Airframe Structure | 4 | 4 | cots |  | 30 mm tube option | Alibaba |  | https://www.alibaba.com/product-detail/30-40mm-Folding-arm-tube-Drone_1600762096177.html | 25.00 | 100.00
1412 | Motor Arm Tube | Airframe Structure | 4 | 2 | cut-to-length | Carbon fiber 3K | 30x28 mm tube, cut to 360 mm | RJXHobby |  | https://www.rjxhobby.com/carbon-fiber/carbon-fiber-tube/rjx-1pcs-colored-3k-carbon-fiber-tube-1000mm-od-21-30mm | 45.00 | 90.00 | 30x28x1000 mm stock, any color; each tube yields two arms
2111 | Attachment Interface Spacer, Left/Right | Supporting Structure | 2 | 2 | 3d-print | PETG-CF
2112 | Quick-Release Interface Plate | Supporting Structure | 3 | 3 | cots | Aluminum |  | Alibaba |  | https://www.alibaba.com/product-detail/Quick-Release-Clip-Plate-Clamp-Quick_1600982145247.html | 34.00 | 102.00
2131 | Attachment Interface Spacer, Bottom | Supporting Structure | 1 | 1 | 3d-print | PETG-CF |  |  |  |  |  |  |  | Has a wiring notch the left/right spacer does not.
2211 | Battery Slider | Supporting Structure | 2 | 2 | 3d-print | PETG-CF
2311 | Main PCB Mount | Supporting Structure | 1 | 1 | 3d-print | PETG-CF
2312 | BC PCB Mount | Supporting Structure | 1 | 1 | 3d-print | PETG-CF
2313 | BC PCB Cover | Supporting Structure | 1 | 1 | 3d-print | PETG-CF
2321 | Altitude Sensor Mount | Supporting Structure | 1 | 1 | 3d-print | PETG-CF
2331 | GNSS Mount Base | Supporting Structure | 1 | 1 | 3d-print | PETG-CF
2332 | GNSS Mount Clamp | Supporting Structure | 1 | 1 | 3d-print | PETG-CF
2341 | PPP Adapter and Beacon Mount | Supporting Structure | 1 | 1 | 3d-print | PETG-CF
2411 | Main Enclosure | Supporting Structure | 1 | 1 | 3d-print | PETG-CF
2412 | Enclosure Top Cap | Supporting Structure | 1 | 1 | 3d-print | PETG-CF
2420 | Enclosure Hinge | Supporting Structure | 2 | 2 | cots | Zinc die-cast |  | JW Winco | GN 237-ZD-30-30-A-SW | https://www.jwwinco.com/en-us/products/3.3-Hinging-latching-locking-of-doors-and-covers/Hinges/GN-237-Zinc-Die-Cast-or-Aluminum-Hinges-Countersunk-Thru-Holes-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 | 10.00 | 20.00
2430 | Enclosure Latch | Supporting Structure | 2 | 2 | cots | Steel |  | McMaster-Carr | 6082A11 | https://www.mcmaster.com/6082A11/ | 10.42 | 20.84
3111 | Motor + ESC, Hobbywing XRotor X6 Plus | Equipment | 4 | 4 | cots |  |  | Hobbywing | XRotor X6 Plus G2 | https://www.hobbywing.com/en/products/x6-plus-g2 | 120.00 | 480.00 |  | Propellers are ordered separately (3112/3122).
3112 | Propeller, Hobbywing MFP 24x8.0, CW | Equipment | 2 | 2 | cots |  |  | Hobbywing | MFP 24x8.0 CW | https://www.hobbywing.com/en/products/mfp-24x80 | 20.00 | 40.00
3122 | Propeller, Hobbywing MFP 24x8.0, CCW | Equipment | 2 | 2 | cots |  |  | Hobbywing | MFP 24x8.0 CCW | https://www.hobbywing.com/en/products/mfp-24x80 | 20.00 | 40.00
3201 | PPP Adapter, CubePilot CubeNode ETH | Equipment | 1 | 1 | cots |  |  | IR-LOCK (CubePilot) |  | https://irlock.com/products/cube-node-eth?variant=42727353122867 | 121.98 | 121.98
3202 | Remote ID Module, DroneBeacon db201 | Equipment | 1 | 1 | cots |  |  | DroneScout (DroneBeacon) | db201 | https://dronescout.co/product/dronebeacon-mavlink-db201-transponder/ | 54.00 | 54.00
3210 | Obstacle Avoidance LiDAR, RPLidar S2L | Equipment | 1 | 1 | cots |  |  | DFRobot |  | https://www.dfrobot.com/product-2617.html | 380.00 | 380.00
3220 | Radar Altimeter, Nanoradar NRA15 | Equipment | 1 | 1 | cots |  |  | Nanoradar | NRA15 | https://www.nanoradar.com/Products_1/4.html | 240.00 | 240.00
3230 | Telemetry Antenna, Front | Equipment | 1 | 0 | cots |  |  |  |  |  |  |  | included with 3280 | Supplied with the SIYI HM30 Standard Combo (3280).
3240 | Telemetry Antenna, Rear | Equipment | 1 | 0 | cots |  |  |  |  |  |  |  | included with 3280 | Supplied with the SIYI HM30 Standard Combo (3280).
3250 | GNSS Module, Primary | Equipment | 1 | 1 | cots |  |  | IR-LOCK (CubePilot) | Here4 | https://irlock.com/products/here4-multiband-rtk-gnss | 288.00 | 288.00 |  | Either listed module is acceptable. The CAD model still shows the retired Wren Mini; update the STEP on the next CAD export.
3251 | GNSS Module, Backup, Mateksys M9N-G4-3100 | Equipment | 1 | 1 | cots |  |  | Mateksys | M9N-G4-3100 | https://www.mateksys.com/?portfolio=m9n-g4-3100 | 125.00 | 125.00 |  | DroneCAN. Not in the CAD model.
3260 | Power Switch, E-Switch PVHC4F23SS344 | Equipment | 1 | 1 | cots |  |  | Digi-Key | PVHC4F23SS344 | https://www.digikey.com/en/products/detail/e-switch/PVHC4F23SS344/24614861 | 16.00 | 16.00
3270 | Gimbal Camera, SIYI A8 mini | Equipment | 1 | 1 | cots |  |  | SIYI |  | https://shop.siyi.biz/products/siyi-a8-mini-gimbal-camera | 251.63 | 251.63
3280 | Telemetry / FPV System, SIYI HM30 | Equipment | 1 | 1 | cots |  |  | SIYI | HM30 Standard Combo | https://shop.siyi.biz/products/siyi-hm30-digital-image-transmission?VariantsId=10748 | 282.04 | 282.04
3290 | Obstacle Avoidance Radar, Nanoradar MR82 | Equipment | 1 | 1 | cots |  |  | Nanoradar | MR82 | https://www.nanoradar.com/Products_1/7.html | 285.00 | 285.00
3310 | Main PCB, assembled | Equipment | 1 | 1 | pcb-assembly |  |  |  |  |  | 400.00 | 400.00 |  | Order via JLCPCB or similar using the KiCad production files; see the Main PCB Assembly Guide.
3312 | Companion Computer, Raspberry Pi 5 | Equipment | 1 | 1 | cots |  | 8 GB RAM | Raspberry Pi |  | https://www.raspberrypi.com/products/raspberry-pi-5/ | 200.00 | 200.00 |  | Mounts on the Main PCB; not a separate CAD part.
3313 | Ethernet Switch, BotBlox GigaBlox Nano | Equipment | 2 | 2 | cots |  |  | BotBlox |  | https://botblox.io/products/micro-gigabit-ethernet-switch | 95.67 | 191.34 |  | Mounts on the Main PCB; not a separate CAD part.
3320 | Battery Connector PCB, assembled | Equipment | 1 | 1 | pcb-assembly |  |  |  |  |  | 83.00 | 83.00 |  | Order via JLCPCB or similar using the KiCad production files; see the BC PCB Assembly Guide.
3324 | BC PCB Heatsink, 5 mm | Equipment | 1 | 1 | laser-cut | Aluminum | 5 mm plate, 116 x 16 mm; the 5 mm variant supersedes the earlier 4 mm one | RapidDirect |  | https://www.rapiddirect.com/ | 16.00 | 16.00 |  | Thermally couples the BC PCB to the chassis; install with thermal paste (CONS-007). Not in the CAD assembly model.
3330 | Flight Controller PCB, assembled | Equipment | 1 | 1 | pcb-assembly |  |  |  |  |  | 25.00 | 25.00 |  | Adapter board; stacks on the Main PCB. Not a separate CAD part.
3331 | Attachment Interface PCB, assembled | Equipment | 3 | 6 | pcb-assembly |  |  |  |  |  | 10.00 | 60.00 | order extras; JLCPCB minimum batch | One per attachment interface (right, left, bottom).
3332 | Flight Controller, Holybro Pix32 v6 | Equipment | 1 | 1 | cots |  |  | Holybro |  | https://holybro.com/products/pix32-v6?variant=43020083527869 | 296.00 | 296.00 |  | Mounts on the FC PCB; not a separate CAD part.
3410 | Battery, Tattu 4.0 14S 30000 mAh | Equipment | 1 | 1 | cots |  |  | Tattu | Tattu 4.0 14S 30000 mAh |  | 735.00 | 735.00 |  | Smart battery with CAN telemetry.
3501 | Remote Control Transmitter | Equipment | 1 | 1 | cots |  |  | RadioMaster | Boxer | https://www.radiomasterrc.com/products/boxer-radio-controller-m2 | 150.00 | 150.00 |  | Builder's choice — any transmitter compatible with the chosen receiver and ELRS/EdgeTX-class link works. The team flies a RadioMaster Boxer.
3510 | Transport Case, Nanuk 976 | Equipment | 1 | 1 | cots |  |  | Nanuk | 976 | https://nanuk.com/products/nanuk-976 | 600.00 | 600.00 |  | Foam cut profiles for the case insert are in task-grant-bounty/Dev-Kit/data/ (Foam_1.dxf, Foam_2.dxf).
4010 | Busbar Pair, Positive + Negative | Harness | 2 | 2 | laser-cut | Copper |  | RapidDirect |  | https://www.rapiddirect.com/ | 30.74 | 61.48 | one positive and one negative busbar per vehicle
HAR-0001 | Harness, Pushbutton | Harness | 1 | 1 | harness
HAR-0002 | Harness, BC PCB Signal | Harness | 1 | 1 | harness
HAR-0003 | Harness, BC PCB SSR | Harness | 1 | 1 | harness
HAR-0004 | Harness, ESC Power FR | Harness | 1 | 1 | harness
HAR-0005 | Harness, ESC Power FL | Harness | 1 | 1 | harness
HAR-0006 | Harness, ESC Power BR | Harness | 1 | 1 | harness
HAR-0007 | Harness, ESC Power BL | Harness | 1 | 1 | harness
HAR-0008 | Harness, ESC Signal FR | Harness | 1 | 1 | harness
HAR-0009 | Harness, ESC Signal FL | Harness | 1 | 1 | harness
HAR-0010 | Harness, ESC Signal BR | Harness | 1 | 1 | harness
HAR-0011 | Harness, ESC Signal BL | Harness | 1 | 1 | harness
HAR-0012 | Harness, Side Payload Right | Harness | 1 | 1 | harness
HAR-0013 | Harness, Side Payload Left | Harness | 1 | 1 | harness
HAR-0014 | Harness, Bottom Payload | Harness | 1 | 1 | harness
HAR-0015 | Harness, Altimeter | Harness | 1 | 1 | harness
HAR-0016 | Harness, 360 LiDAR | Harness | 1 | 1 | harness
HAR-0017 | Harness, Front Radar | Harness | 1 | 1 | harness
HAR-0018 | Harness, HM30 Power | Harness | 1 | 1 | harness
HAR-0019 | Harness, HM30 Signal A | Harness | 1 | 1 | harness
HAR-0020 | Harness, HM30 Signal B | Harness | 1 | 1 | harness
HAR-0021 | Harness, Navigation Primary GNSS | Harness | 1 | 1 | harness
HAR-0022 | Harness, Navigation Backup GNSS | Harness | 1 | 1 | harness
HAR-0023 | Harness, PPP2ETH A | Harness | 1 | 1 | harness
HAR-0024 | Harness, PPP2ETH B | Harness | 1 | 1 | harness
HAR-0025 | Harness, PPP2ETH C | Harness | 1 | 1 | harness
HAR-0026 | Harness, Remote ID | Harness | 1 | 1 | harness
HAR-0027 | Harness, SIYI Camera | Harness | 1 | 1 | harness
HAR-0028 | Harness, Antenna | Harness | 1 | 1 | harness
HSUP-001 | XT30 Male Connector, Amass XT30U-M | Harness | 1 | 1 | cots |  |  | TME | XT30U-M | https://www.tme.com/us/en-us/details/xt30u-m/dc-power-connectors/amass/ | 0.83 | 0.83
HSUP-002 | XT60 Male Connector, Amass XT60U-M | Harness | 4 | 4 | cots |  |  | TME | XT60U-M | https://www.tme.com/us/en-us/details/xt60u-m/dc-power-connectors/amass/ | 0.70 | 2.80
HSUP-003 | Pluggable Terminal Block, Phoenix PTSM 0,5/2-P-2,5 WH | Harness | 1 | 1 | cots |  |  | Mouser | 1704853 | https://mou.sr/3TUNxPr
HSUP-004 | Pluggable Terminal Block, Phoenix PTSM 0,5/4-P-2,5 WH | Harness | 18 | 18 | cots |  |  | Mouser | 1704857 | https://mou.sr/4bSpp8f
HSUP-005 | Pluggable Terminal Block, Phoenix PTSM 0,5/5-P-2,5 WH | Harness | 5 | 5 | cots |  |  | Mouser | 1704858 | https://mou.sr/4nxik2l
HSUP-006 | Pluggable Terminal Block, Phoenix PTSM 0,5/6-P-2,5 WH | Harness | 5 | 5 | cots |  |  | Mouser | 1704859 | https://mou.sr/44ach9V
HSUP-007 | Hook-Up Wire Kit, 26 AWG PTFE, 10 colors | Harness | 1 | 1 | cots |  | 15 feet per color | Remington Industries |  | https://www.remingtonindustries.com/hook-up-wire/custom-hook-up-wire-26-awg-ptfe-stranded-kit-2-spool-sizes-available-choose-10-colors/
HSUP-008 | Molex 12-Pin Connector, 207760-1281 | Harness | 6 | 6 | cots |  |  | Mouser | 207760-1281 | https://www.mouser.com/ProductDetail/Molex/207760-1281 | 1.51 | 9.06
HSUP-009 | Molex MLP Receptacle Housing, 204523-1201, 12 circuits | Harness | 6 | 6 | cots |  |  | Mouser | 204523-1201 | https://www.mouser.com/ProductDetail/Molex/204523-1201 | 0.42 | 2.52 |  | Cable-side connector; does not go on the PCB.
HSUP-010 | Spring-Loaded Connector, Mill-Max 813-22-010-30-000101 | Harness | 6 | 6 | cots |  |  | Mouser | 813-22-010-30-000101 | https://www.mouser.com/ProductDetail/Mill-Max/813-22-010-30-000101 | 8.60 | 51.60 |  | Can populate with just one.
HSUP-011 | SLC Target Connector, Mill-Max 419-10-210-30-054000 | Harness | 6 | 6 | cots |  |  | Mouser | 419-10-210-30-054000 | https://www.mouser.com/ProductDetail/Mill-Max/419-10-210-30-054000 | 3.63 | 21.78 |  | Can populate with just one.
HSUP-012 | Attachment Interface Cable, Molex 79758-1149 | Harness | 50 | 50 | cots |  |  | Mouser | 79758-1149 | https://www.mouser.com/ProductDetail/Molex/79758-1149 | 1.29 | 64.50
HSUP-013 | JST GH Pre-Made Cable Assortment | Harness | 1 | 1 | cots |  | kit covering positions 3, 4, 5, 6, 9 | Amazon |  | https://www.amazon.com/dp/B07PBHN7TM
FAST-001 | Rivet, 4 mm, for 1-2.5 mm grip | Fasteners | 26 | 26 | cots |  |  | McMaster-Carr | 97525A224 | https://www.mcmaster.com/97525A224/
FAST-002 | Rivet, 4 mm, for 2.5-4.5 mm grip | Fasteners | 10 | 10 | cots |  |  | McMaster-Carr | 97525A251 | https://www.mcmaster.com/97525A251
FAST-003 | Rivet, 4 mm, for 4.5-6.4 mm grip | Fasteners | 10 | 10 | cots |  |  | McMaster-Carr | 97525A226 | https://www.mcmaster.com/97525A226
FAST-004 | Socket Head Screw M3x10 | Fasteners | 8 | 8 | cots |  |  | McMaster-Carr | 91292A113 | https://www.mcmaster.com/91292A113
FAST-005 | Flanged Button Head Screw M4x10 | Fasteners | 16 | 16 | cots |  |  | McMaster-Carr | 92095A190 | https://www.mcmaster.com/92095A190
FAST-006 | Button Head Hex-Drive Screw M2x4 | Fasteners | 12 | 12 | cots |  |  | McMaster-Carr | 92095A451 | https://www.mcmaster.com/92095A451/
FAST-007 | Socket Head Screw M3x12 | Fasteners | 8 | 8 | cots |  |  | McMaster-Carr | 91292A114 | https://www.mcmaster.com/91292A114
FAST-008 | Socket Head Screw M3x8 | Fasteners | 79 | 79 | cots |  |  | McMaster-Carr | 91292A112 | https://www.mcmaster.com/91292A112
FAST-009 | Socket Head Screw M3x40 | Fasteners | 16 | 16 | cots |  |  | McMaster-Carr | 91292A024 | https://www.mcmaster.com/91292A024
FAST-010 | Socket Head Screw M2.5x6 | Fasteners | 4 | 4 | cots |  |  | McMaster-Carr | 91292A010 | https://www.mcmaster.com/91292A010/
FAST-011 | Hex Drive Flat Head Screw M3x10 | Fasteners | 8 | 8 | cots |  |  | McMaster-Carr | 92125A130 | https://www.mcmaster.com/92125A130/
FAST-012 | Socket Head Screw M4x8 | Fasteners | 8 | 8 | cots |  |  | McMaster-Carr | 91292A108 | https://www.mcmaster.com/91292A108
FAST-013 | Socket Head Screw M2x6 | Fasteners | 4 | 4 | cots |  |  | McMaster-Carr | 91292A832 | https://www.mcmaster.com/91292A832/
FAST-014 | Flanged Button Head Hex-Drive Screw M3x6 | Fasteners | 23 | 23 | cots |  |  | McMaster-Carr | 97654A674 | https://www.mcmaster.com/products/97654a674/
FAST-015 | Socket Head Hex-Drive Screw M2x5 | Fasteners | 4 | 4 | cots |  |  | McMaster-Carr | 92855A837 | https://www.mcmaster.com/92855A837/
FAST-016 | Socket Head Hex-Drive Screw M2.5x8 | Fasteners | 4 | 4 | cots |  |  | McMaster-Carr | 91292A012 | https://www.mcmaster.com/91292A012/
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

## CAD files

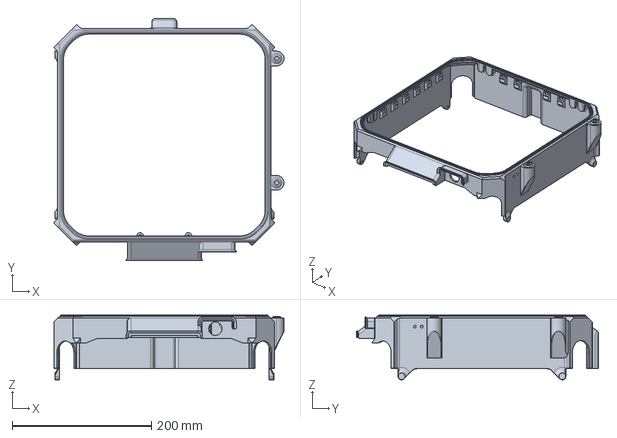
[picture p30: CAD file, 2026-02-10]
src/quiver/supporting_structure/cockpit_enclosure/steps/2411_main_enclosure.step
330.2 x 347.4 x 93.0 mm

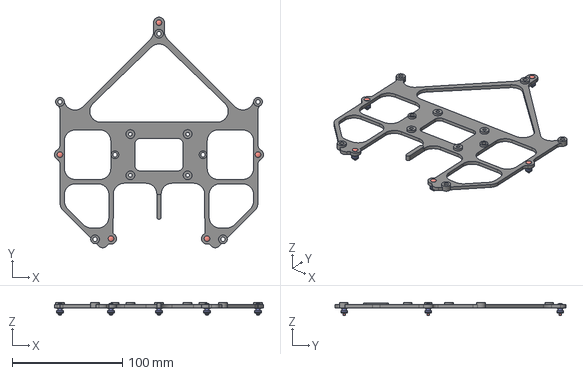
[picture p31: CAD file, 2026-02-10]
src/quiver/supporting_structure/equipment_mount/steps/2311_main_pcb_mount.step
190.0 x 209.6 x 11.8 mm
Rubber_Spacer_3 x 5
Snap_In_Lock_Pin x 5

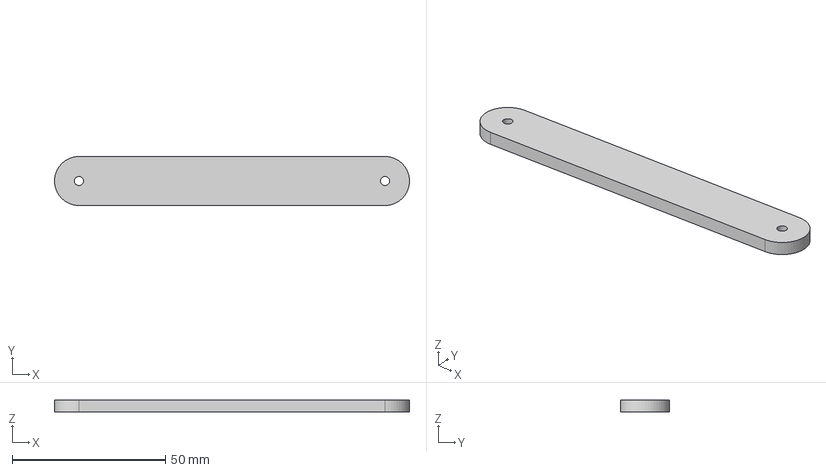
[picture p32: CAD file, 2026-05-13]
docs/Manufacturing/Assembly-Guides/assets/models/structural/3324_1.step
116.0 x 16.0 x 4.00 mm

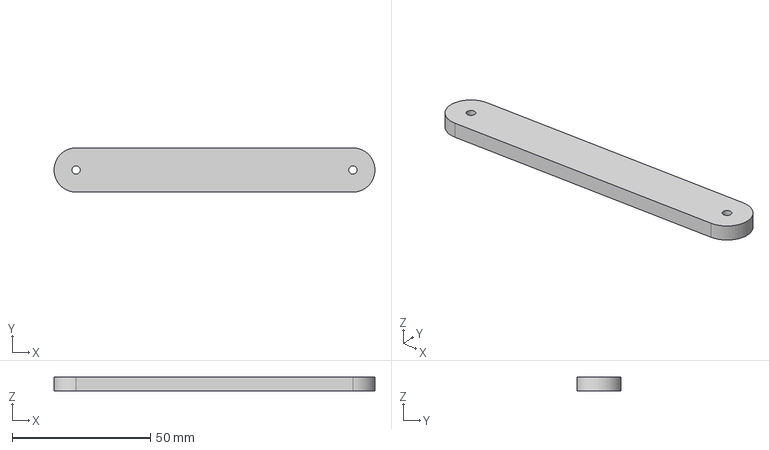
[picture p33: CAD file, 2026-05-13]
src/manufacturing/3324_bc_pcb_heatsink.step
116.0 x 16.0 x 5.00 mm

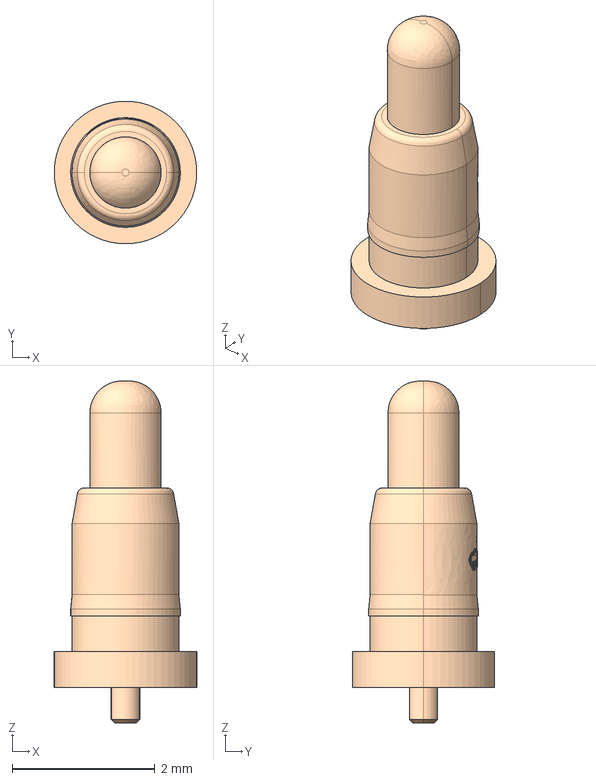
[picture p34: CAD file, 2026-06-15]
src/pcb/attach_pcb/EASYEDA_MODELS/TESTPOIT-SMD_BD2.0-D0.4.step
2.00 x 2.00 x 4.80 mm

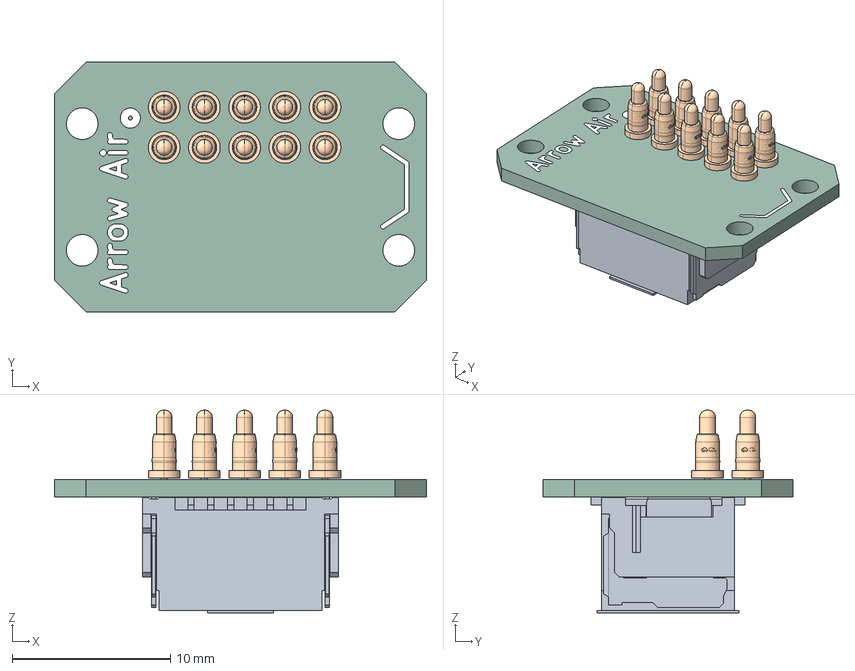
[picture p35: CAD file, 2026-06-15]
src/pcb/attach_pcb/QuiverAttachPCB_V1_4.step
23.5 x 15.8 x 12.8 mm
TESTPOIT-SMD_BD2.0-D0.4 x 10
QuiverAttachPCB_silkscreen x 2
QuiverAttachPCB_PCB

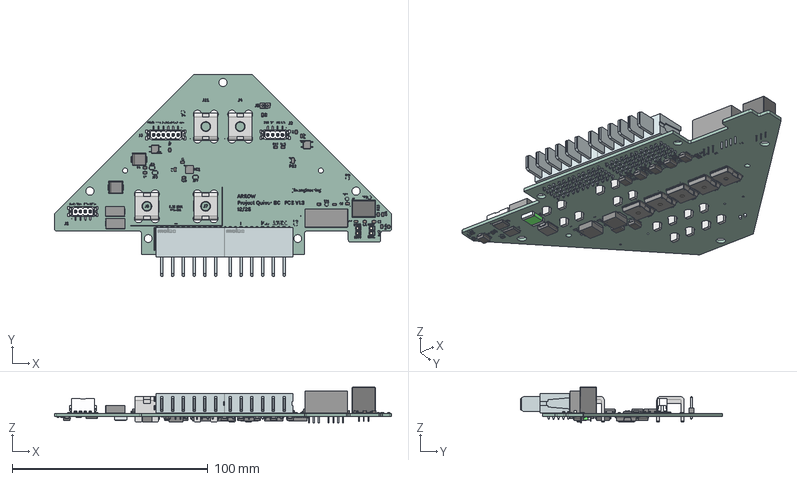
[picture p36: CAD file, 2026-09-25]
src/pcb/battery_pcb/Front_PCB_V1.3.step
172.2 x 103.2 x 18.3 mm
R_0805_2012Metric x 30
Pins x 2
C_0805_2012Metric x 5
APT2012LVBC_D x 4
LeadsArray
ThermalPin
PinsArrayLR x 3
PinsArrayTB
ptsm_0.5-4-hv-2.5-smd_wh x 2
SMC_L7.1-W6.2-LS8.1-R-RD x 2
AMT0450003DB0000G x 4
ptsm_0.5-6-hv-2.5-smd_wh
Leads x 7
TSR_0.6-48120WI
PinsArrayL
FilletPinR
D_SMB x 8
POWERPAK-SO-8_L5.9-W4.9-P1.27-LS6.2-BL x 2
RES_PWR163_BRN x 2
Infineon Logo Adjustable x 5
term1
term2
SMC_L6.9-W5.9-H2.1-LS7.9
Front_PCB_silkscreen
Front_PCB_PCB

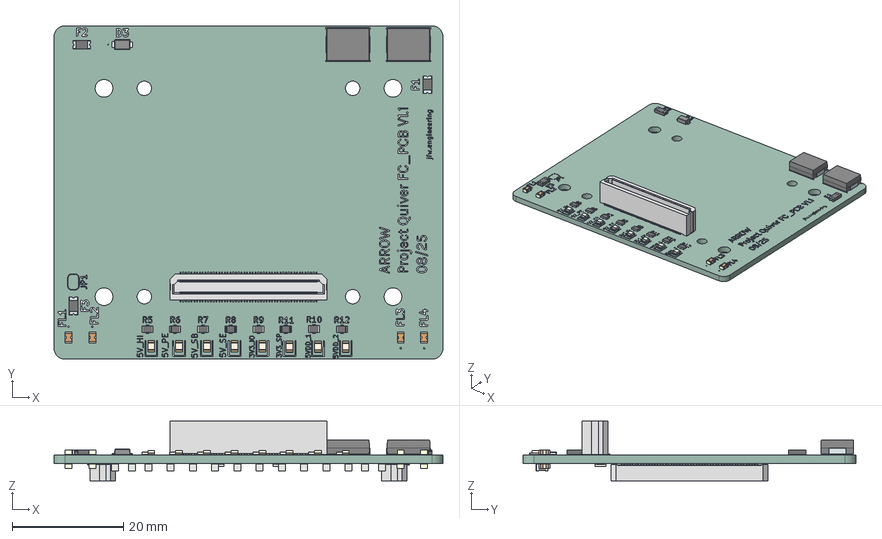
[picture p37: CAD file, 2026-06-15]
src/pcb/fc_pcb/Quiver_PT3_FC_PCB.step
70.0 x 60.0 x 10.8 mm
Intersect x 3
Terminal x 3
APT2012LVBC_D x 8
axk5s00347y
R_0805_2012Metric x 12
NFM21PC104R1E3D x 8
FilletPin1 x 2
FilletPin2 x 2
DFLS240L-7
C_0805_2012Metric x 14
axk5s00047y x 2
Quiver_PT3_FC_PCB_silkscreen
Quiver_PT3_FC_PCB_PCB

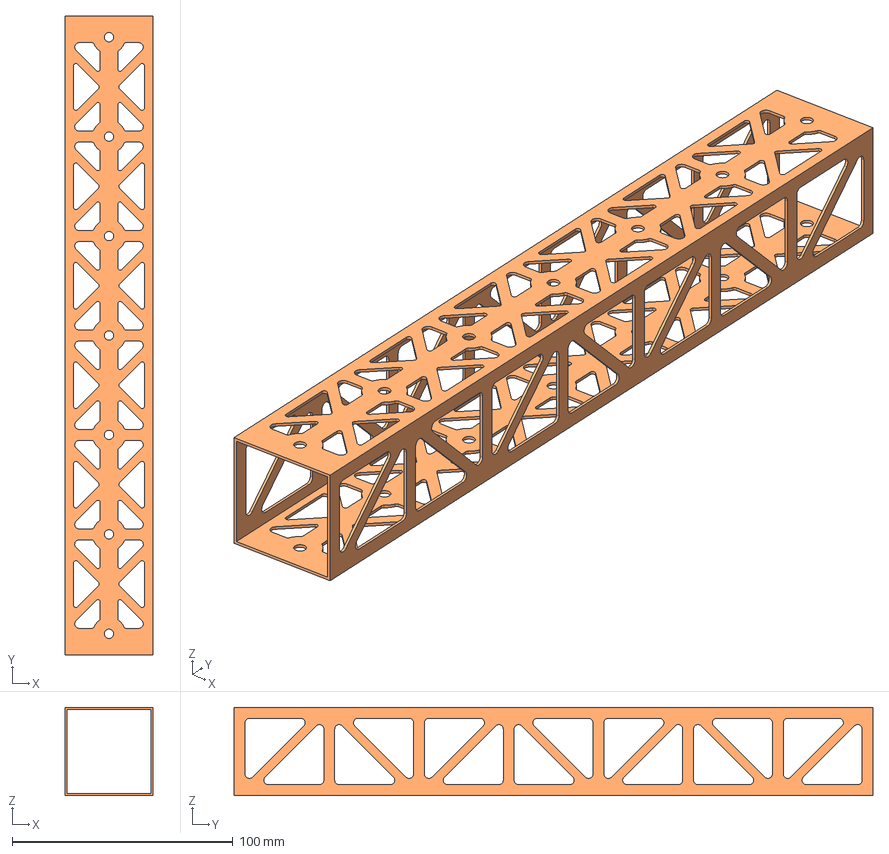
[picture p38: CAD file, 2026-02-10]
src/quiver/airframe_structure/beams/steps/1211_cw_long.step
40.0 x 289.2 x 40.0 mm

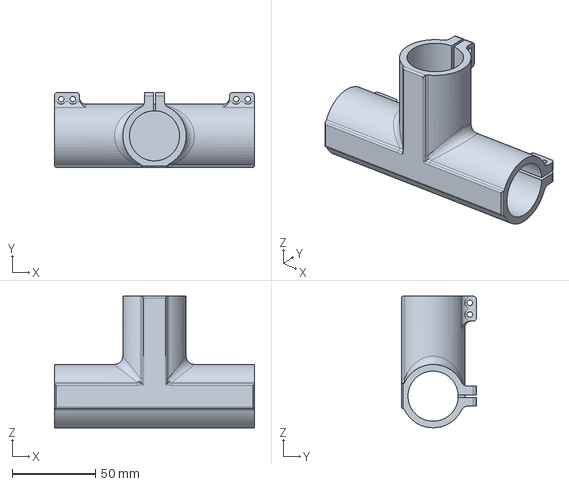
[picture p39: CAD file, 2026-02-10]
src/quiver/airframe_structure/landing_gear/steps/1340_tube_joint.step
120.0 x 45.0 x 79.0 mm

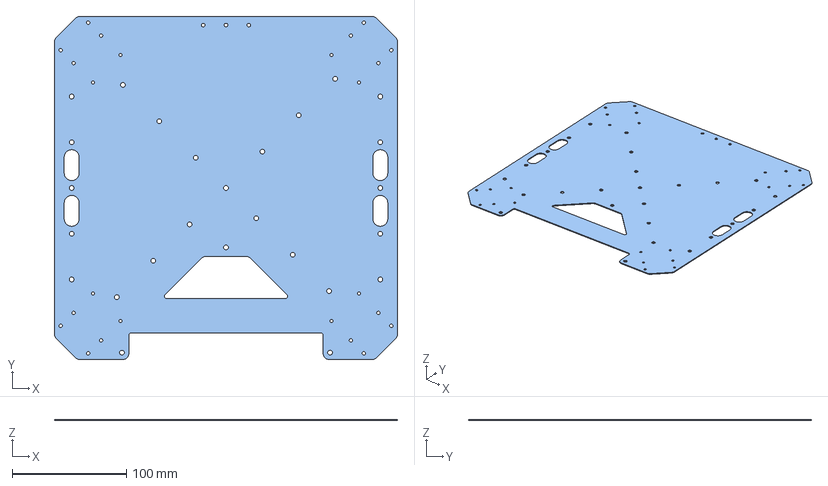
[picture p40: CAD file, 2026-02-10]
src/quiver/airframe_structure/plates/steps/1112_middle_plate.step
300.0 x 300.0 x 1.00 mm

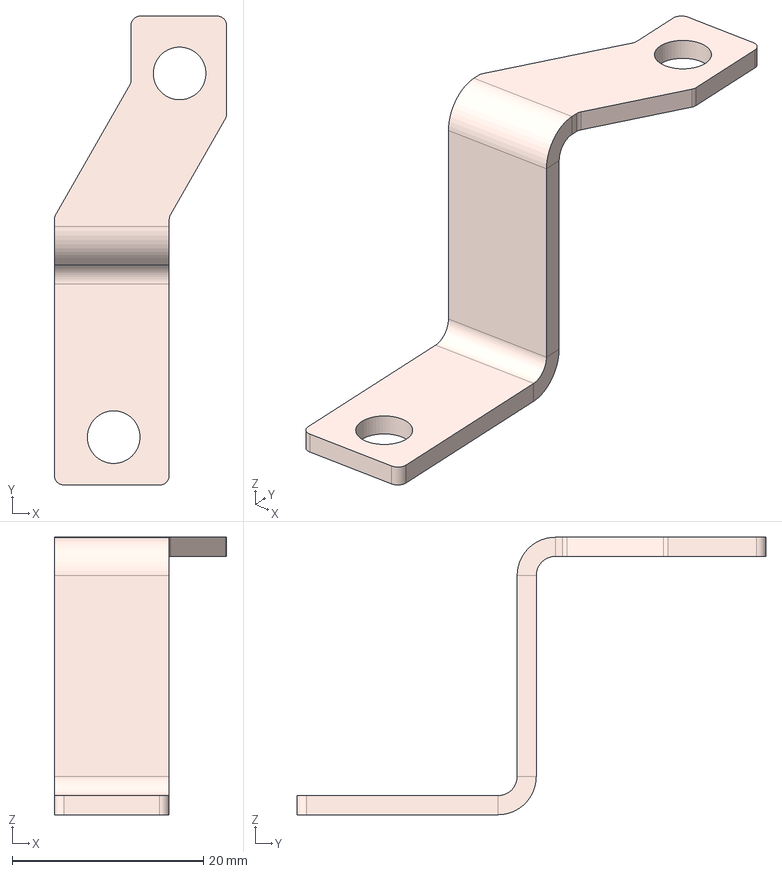
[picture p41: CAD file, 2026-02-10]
src/quiver/harness/steps/4010_busbar_positive.step
18.0 x 49.0 x 29.0 mm

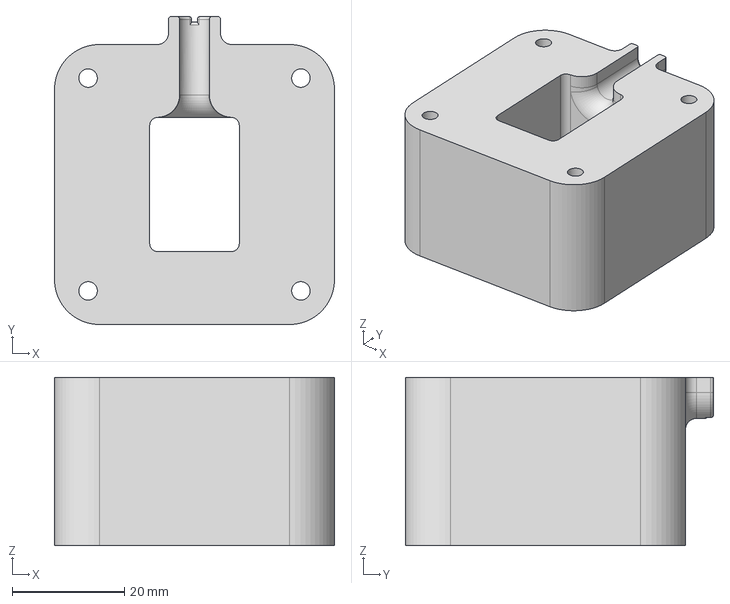
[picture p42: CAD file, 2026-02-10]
src/quiver/supporting_structure/attachment_interface/steps/2131_attach_spacer_bottom.step
50.0 x 55.0 x 30.0 mm

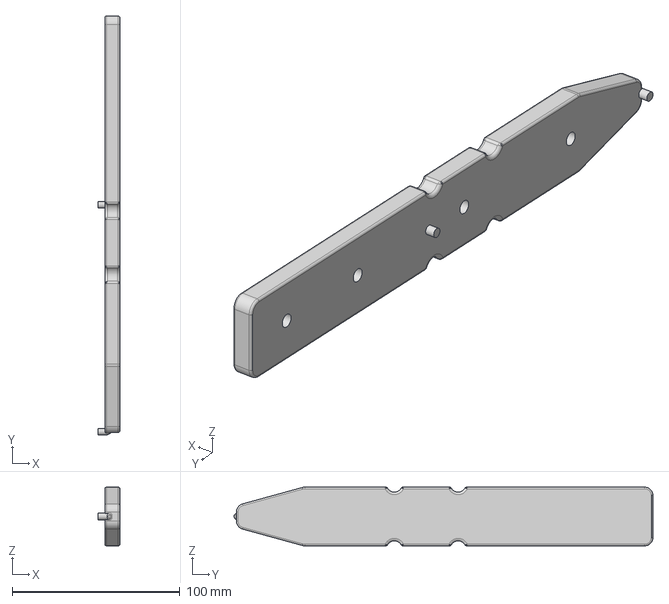
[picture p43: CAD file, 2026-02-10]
src/quiver/supporting_structure/battery_slider/steps/2211_battery_slider.step
13.0 x 249.4 x 35.0 mm

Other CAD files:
src/quiver/supporting_structure/cockpit_enclosure/steps/2412_enclosure_top_cap.step
src/quiver/supporting_structure/equipment_mount/steps/2331_gnss_mount_base.step
task-grant-bounty/Dev-Kit/data/Foam_1.dxf
task-grant-bounty/pt1/electronics/0001-PDB_V1/project-data/3D STEP/Quiver_PDB_01_reduced.step
docs/Archive/PT3-Assembly-Guides/structural-assembly/assets/models/part1.step
docs/Archive/PT3-Assembly-Guides/structural-assembly/assets/models/part2.step
docs/Archive/PT3-Assembly-Guides/structural-assembly/assets/models/part3.step
docs/Archive/PT3-Assembly-Guides/structural-assembly/assets/models/part4.step
docs/Archive/PT3-Assembly-Guides/structural-assembly/assets/models/part5_6.step
docs/Archive/PT3-Assembly-Guides/structural-assembly/assets/models/part7_8.step
docs/Manufacturing/Assembly-Guides/assets/models/structural/1111.step
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

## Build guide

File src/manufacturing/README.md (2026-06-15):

# Manufacturing

DXFs, cut sheets, and fabrication drawings for CNC and laser-cut parts.

> **Status:** no fabrication drawings are checked in yet — part geometry
> currently lives in the STEP files under
> [`src/quiver/`](../quiver/) (e.g.
> `quiver/airframe_structure/plates/steps/1111_upper_plate.step`), and
> Dev-Kit foam cut profiles are in
> [`task-grant-bounty/Dev-Kit/data/`](../../task-grant-bounty/Dev-Kit/data/).
> Contributions of per-part DXFs and drawings are welcome.

## Metal parts

The following BOM subcategories contain CNC or laser-cut metal parts:

| BOM | Subcategory | Material | Parts |
|---|---|---|---|
| 1100 | Plates | Aluminum (2–4mm) | Upper, middle, and lower plates |
| 1200 | Beams | Aluminum tube (40x40x2mm, 30x2mm) | Cockpit beams, battery walls |
| 1400 | Motor Arm | Aluminum (30mm) | Arm connectors |
| 1300 | Landing Gear | Aluminum (30mm) | Main adapters |

## Organization

Store DXF and drawing files named with BOM prefixes matching the CAD
assembly convention:

```
manufacturing/
    1111_upper_plate.dxf
    1112_middle_plate.dxf
    1113_lower_plate.dxf
    ...
```

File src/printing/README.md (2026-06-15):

# 3D Printing

Slicer profiles and print settings for 3D-printed Quiver parts.

> **Status:** no slicer profiles are checked in yet — print the parts
> from the STEP files under [`src/quiver/`](../quiver/) using the
> material noted below. Tested profile contributions are welcome.

## 3D-printed parts

The following BOM subcategories contain 3D-printed components (PETG-CF
unless noted otherwise):

| BOM | Subcategory | Parts |
|---|---|---|
| 1300 | Landing Gear | Tube joints |
| 2100 | Attachment Interface | Spacers |
| 2200 | Battery Slider | Battery sliders |
| 2300 | Equipment Mount | PCB mounts, sensor mounts, camera mount |
| 2400 | Cockpit Enclosure | Main enclosure, top cap, anchors, clips |

## Organization

Store slicer profiles and settings grouped by printer or material. For
example:

```
printing/
    bambu_x1c_petg_cf.json
    prusa_mk4_petg_cf.3mf
```

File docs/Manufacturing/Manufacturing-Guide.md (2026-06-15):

---
title: Dev-Kit Manufacturing Guide
sidebar_label: Dev-Kit Manufacturing Guide
sidebar_position: 2
---

# Dev-Kit Manufacturing Guide

## PCB Fabrication and Assembly

Build the vehicle PCBs using the standalone PCB assembly guides. These guides are the canonical source for ordering notes, interactive BOMs, stencil/reflow guidance, inspection images, and PCB-specific manual assembly steps.

- [Main PCB Assembly Guide](./PCB-Assembly-Guides/Main-PCB.md)
- [Battery Control PCB Assembly Guide](./PCB-Assembly-Guides/BC-PCB.md)
- [Flight Controller PCB Assembly Guide](./PCB-Assembly-Guides/FC-PCB.md)

This Dev-Kit Manufacturing Guide covers how the completed PCBs are installed into the vehicle during general assembly.

## Harness Fabrication

Build harnesses using the standalone [Harness Manufacturing Guide](./Harness-Manufacturing-Guide.mdx). It is the canonical source for nailboard diagrams, BOMs, wire prep, termination, and pinout maps.

This Dev-Kit Manufacturing Guide keeps only vehicle-side routing and installation notes, placed in the assembly steps where each harness is installed.

## BOM for the Assembly

The complete, versioned bill of materials lives on the
[Bill of Materials](./BOM.md) page, generated from the BOM master data
in [`bom/`](https://github.com/Arrow-air/project-quiver/tree/main/bom).
It covers structure parts, fasteners, equipment, harnesses, consumables,
and tools, with supplier links and a downloadable procurement CSV.

-------

## Preparation

### 1111, 1112 & 1113 - Rack Plates
- All three are aluminum 6 series sheets, laser cut, sanded.
- Bounding box dimension is 300x300 mm for each.
- Qty: 1 each.
- Reference supplier: [Rapiddirect](https://www.rapiddirect.com/)

| | 1111 (Upper Plate) | 1112 (Mid Plate) | 1113 (Lower Plate)|
|--|--|--|--|
|Thickness| 1 mm| 1 mm| 4 mm|
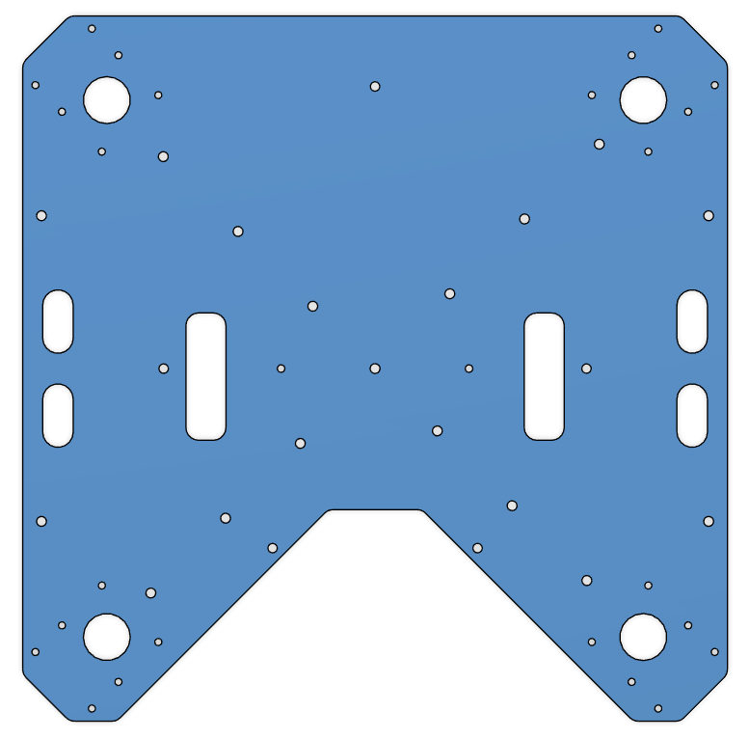
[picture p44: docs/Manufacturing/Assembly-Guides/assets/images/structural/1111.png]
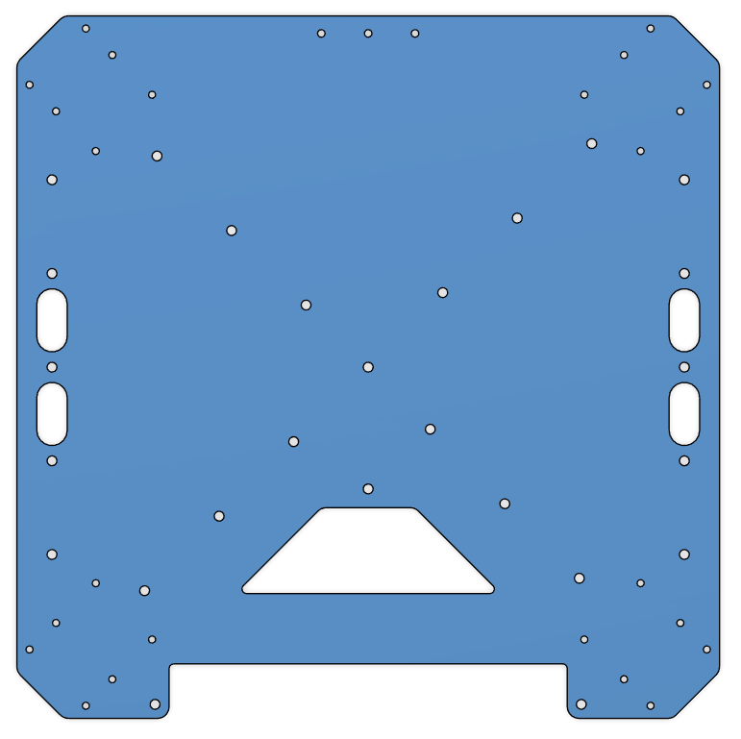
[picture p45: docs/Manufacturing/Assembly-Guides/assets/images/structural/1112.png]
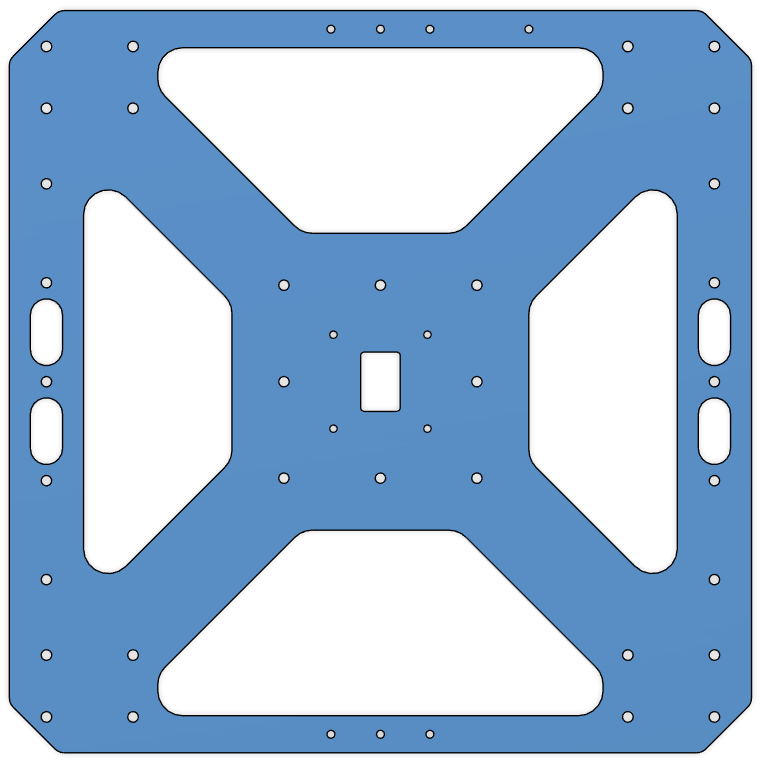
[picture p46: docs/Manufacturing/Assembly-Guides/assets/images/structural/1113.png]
| Image|  |  |  |
| CAD File|[1111](Assembly-Guides/assets/models/structural/1111.step)| [1112](Assembly-Guides/assets/models/structural/1112.step)| [1113](Assembly-Guides/assets/models/structural/1113.step)|
---
### 1211, 1212 & 1213 - Cockpit Support Beams
- All three are aluminum 6 series, 40x40x1 mm square tubes, laser cut, sanded.
- Part 1211; Qty: 1.
- Parts 1212 and 1213 are identical; Qty: 2.
- Reference supplier: [Rapiddirect](https://www.rapiddirect.com/)

| | 1211 (Cockpit Support Beam CW Long) | 1212 & 1213 (Cockpit Support Beam CCW Back & Front) |
|--|--|--|
|Length|289.2 mm|124.2 mm|
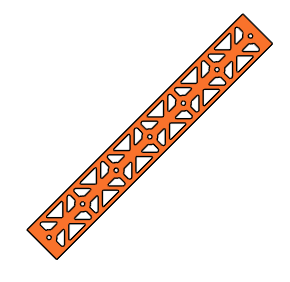
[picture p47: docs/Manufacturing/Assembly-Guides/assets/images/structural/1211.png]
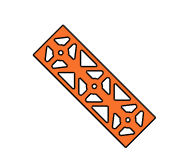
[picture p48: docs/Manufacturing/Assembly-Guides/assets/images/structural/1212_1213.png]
| Image|  |  |
| CAD File|[1211](Assembly-Guides/assets/models/structural/1211.step)| [1212 & 1213](Assembly-Guides/assets/models/structural/1212_1213.step)|
---
### 1221 & 1222 - Battery Walls
- Both are aluminum 6 series, 1000x30x2 mm rectangular tubes, laser cut, sanded.
- Length is 300 mm for each.
- Parts are identical; Qty: 2.
- Reference supplier: [Rapiddirect](https://www.rapiddirect.com/)

| | 1221 & 1222 (Battery Wall Left & Right) |
|--|--|
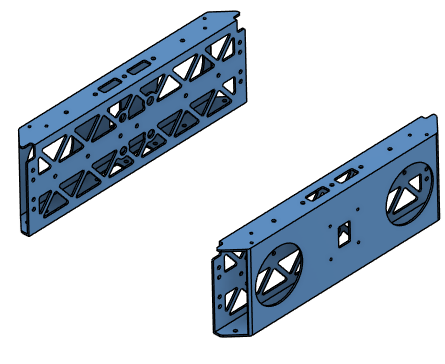
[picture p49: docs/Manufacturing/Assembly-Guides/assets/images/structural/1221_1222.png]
| Image|  |
| CAD File|[1221 & 1222](Assembly-Guides/assets/models/structural/1221_1222.step)|
---
### 1311, 1312, 1313 & 1314 - Landing Gear Vertical Tubes
- Carbon-fiber tubes, 30 mm diameter, 1 mm thickness.
- Length is 400 mm for each.
- Parts are identical; Qty: 4.
  - Note: Order parts pre-cut to the specified length if available; otherwise, cut to length.
---
### 1321 & 1322 - Landing Gear Horizontal Tubes
- Carbon-fiber tubes, 30 mm diameter, 1 mm thickness.
- Length is 500 mm for each.
- Parts are identical; Qty: 2.
  - Note: Order parts pre-cut to the specified length if available; otherwise, cut to length.
---
### 1331, 1332, 1333 & 1334 - Landing Gear Main Adapters
- Off-the-shelf component.
- 30 mm option.
- Product Link: [Link](https://www.rjxhobby.com/rjx-1pcs-20mm-quick-release-tripod-aluminum-tilt-fixed-seat-landing-gear-connector-1)
- Qty: 4.

:::note
- This product became available in RJXHobby catalog after a customized order for 30 mm tube diameter.
- If not available in the catalog, contact RJXHobby for the customization.
- Request 30 mm diameter variant of [this product](https://www.rjxhobby.com/rjx-1pcs-20mm-quick-release-tripod-aluminum-tilt-fixed-seat-landing-gear-connector-1) with bolt pattern of 30 mm version of [this one](https://www.rjxhobby.com/rjxhobby-1pcs-20mm-25mm-30mm-landing-gear-vertical-mount-base-nozzle-connecting-rod-fixing-parts-for-rc-plant-agriculture-uav-drone).
:::

:::note
If detachable landing gear is not favored, you may use 30 mm version of [this product](https://www.rjxhobby.com/rjxhobby-1pcs-20mm-25mm-30mm-landing-gear-vertical-mount-base-nozzle-connecting-rod-fixing-parts-for-rc-plant-agriculture-uav-drone).
:::

| 1331, 1332, 1333 & 1334 (Landing Gear Main Adapter) |
|--|
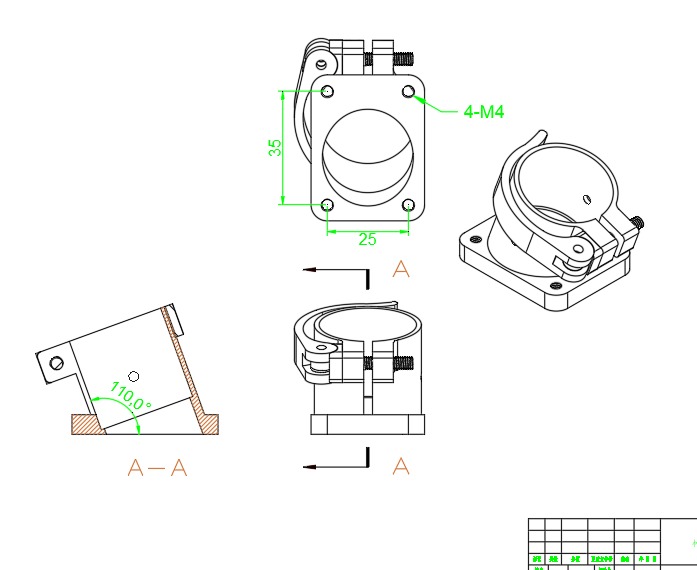
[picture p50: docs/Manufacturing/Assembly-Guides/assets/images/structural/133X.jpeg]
|  |
---
### 1341, 1342, 1343 & 1344 - Landing Gear Tube Joints

- Off-the-shelf component.
- Product Link: [Link](https://www.innloi.com/productinfo/448455.html)
- Qty: 4.

| | 1341, 1342, 1343 & 1344  (Landing Gear Tube Joint) |
|--|--|
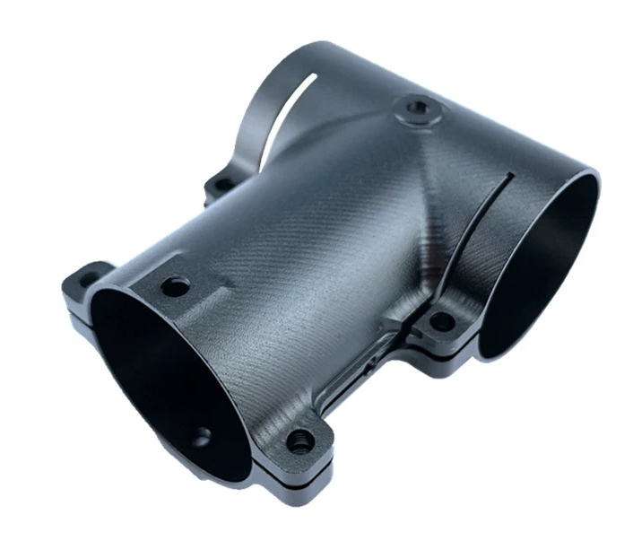
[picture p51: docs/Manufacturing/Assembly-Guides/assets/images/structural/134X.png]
| Image|  |
---
### 1351, 1352, 1353 & 1354 - Landing Gear Foam Wraps.
- Pipe insulation foam, 28 mm inner diameter, 46 mm outer diameter.
- Length is 103 mm each.
- Parts are identical; Qty: 4.
- Cut from stock material to length.
- Product Link: [Link](https://a.co/d/06ePWuUq)

| 1351, 1352, 1353 & 1354 (Landing Gear Foam Wrap) |
|--|
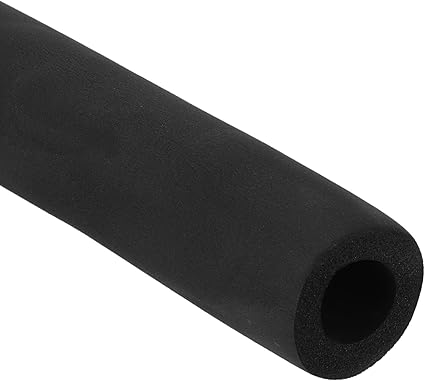
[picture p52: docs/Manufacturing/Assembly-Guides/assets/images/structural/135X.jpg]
|  |
---
### 1411, 1421, 1431 & 1441 - Motor Arm Foldable Connectors
- 30 mm tube diameter version.
- Parts are identical; Qty: 4.
- Product Link: [Link](https://www.alibaba.com/product-detail/30-40mm-Folding-arm-tube-Drone_1600762096177.html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)

| 1411, 1421, 1431 & 1441 (Motor Arm Foldable Connectors) |
|--|
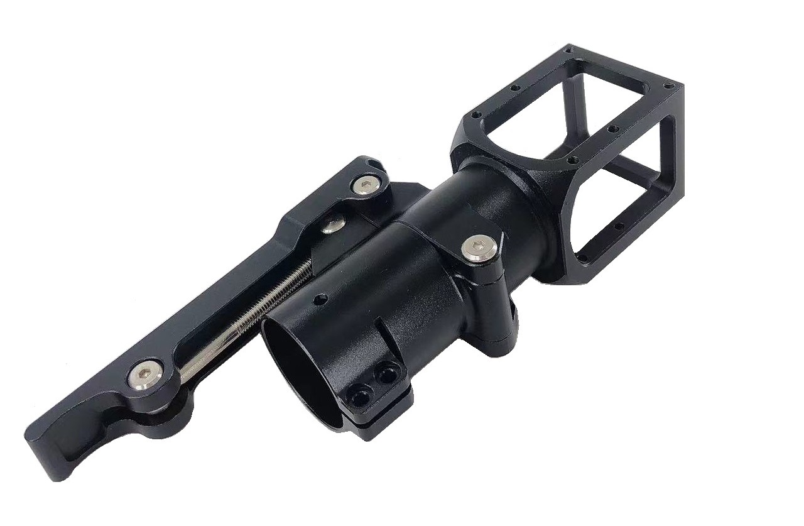
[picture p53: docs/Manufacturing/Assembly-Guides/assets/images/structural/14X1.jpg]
|  |
---
### 1412, 1422, 1432 & 1442 - Motor Arms
- Carbon-fiber tubes, 30 mm diameter, 1 mm thickness.
- Length is 360 mm for each.
- Parts are identical; Qty: 4.
  - Note: Order parts pre-cut to the specified length if available; otherwise, cut to length.
---
### 2111, 2121 & 2131 - Attachment Interface Spacers
- 3D printed.
- PETG-CF.
- Use 6 wall loops.
- Parts 2111 and 2121 are identical; Qty: 2.
- Part 2131; Qty: 1.

| | 2111 & 2121 (Attachment Interface Spacers, Left and Right) | 2131 (Attachment Interface Spacer, Bottom) |
|--|--|--|
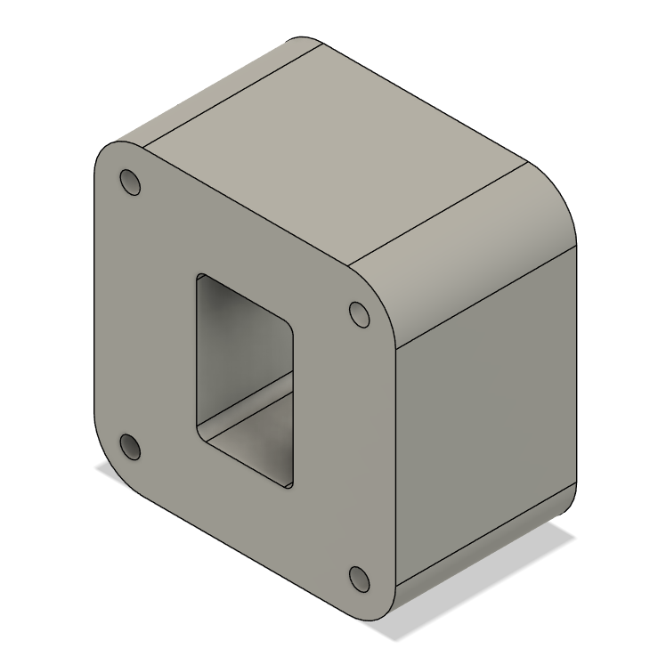
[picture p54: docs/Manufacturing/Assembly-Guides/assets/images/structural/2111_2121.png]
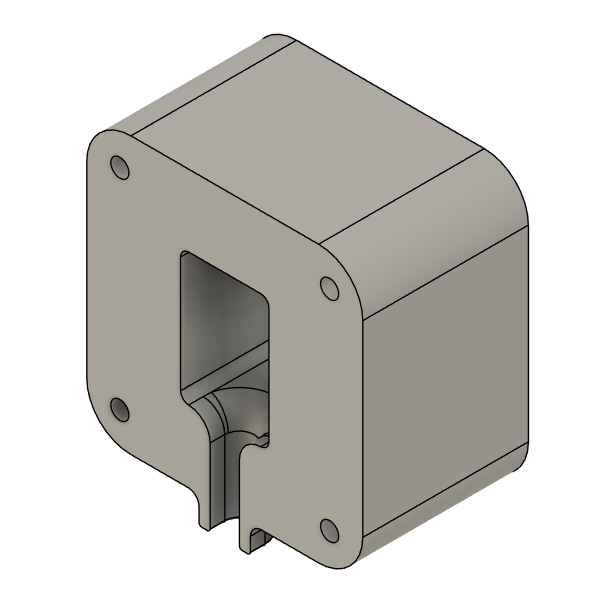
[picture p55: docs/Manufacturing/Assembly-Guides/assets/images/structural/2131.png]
| Image|  |  |
| CAD File|[2111 & 2121](Assembly-Guides/assets/models/structural/2111_2121.stl)| [2131](Assembly-Guides/assets/models/structural/2131.stl)|
---
### 2112, 2122 & 2132 - Attachment Interfaces
- Parts are identical, order 3 parts.
- Select "Without PCB Board" option.
- Product Link: [Link](https://www.alibaba.com/product-detail/Quick-Release-Clip-Plate-Clamp-Quick_1600982145247.html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)

| 2112, 2122 & 2132 (Attachment Interface) |
|--|
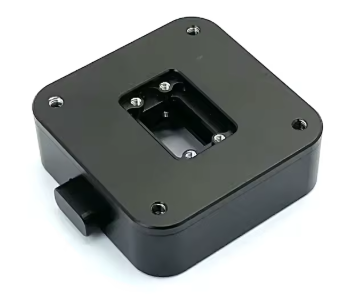
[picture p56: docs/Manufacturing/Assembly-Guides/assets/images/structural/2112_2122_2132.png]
|  |
---
### 2211 & 2212 - Battery Sliders
- 3D printed.
- PETG-CF.
- Use 6 wall loops.
- Parts are identical; Qty: 2.

| | 2211 & 2212  (Battery Slider) |
|--|--|
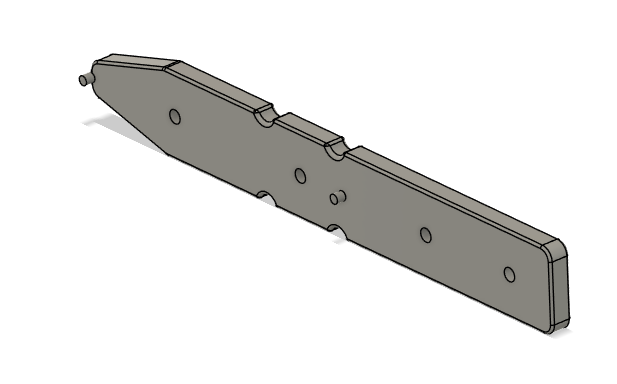
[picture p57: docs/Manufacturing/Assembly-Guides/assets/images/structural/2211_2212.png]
| Image|  |
| CAD File|[2211 & 2212](Assembly-Guides/assets/models/structural/2211_2212.stl)|
---
### 2311 - Main PCB Mount
- 3D printed.
- PETG-CF.
- Use 6 wall loops.
- Qty: 1.

| | 2311  (Main PCB Mount) |
|--|--|
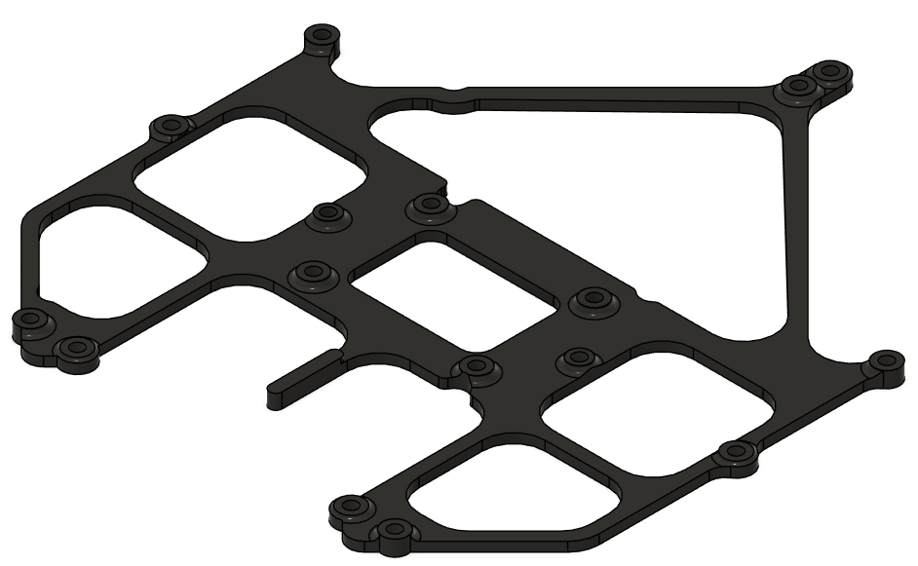
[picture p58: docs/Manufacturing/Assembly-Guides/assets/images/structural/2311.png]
| Image|  |
| CAD File|[2311](Assembly-Guides/assets/models/structural/2311.stl)|
---
### 2312 - Battery Connector PCB Mount
- 3D printed.
- PETG-CF.
- Use 6 wall loops.
- Qty: 1.

| | 2312  (BC PCB Mount) |
|--|--|
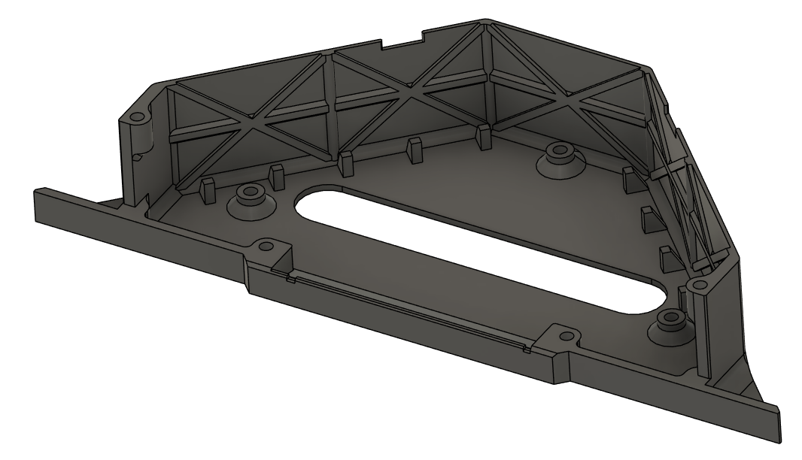
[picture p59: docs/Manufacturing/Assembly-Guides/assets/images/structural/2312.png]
| Image|  |
| CAD File|[2312](Assembly-Guides/assets/models/structural/2312.stl)|
---
### 2313 - Battery Connector PCB Cover
- 3D printed.
- PETG-CF.
- Use 6 wall loops.
- Qty: 1.

| | 2313  (BC PCB Cover) |
|--|--|
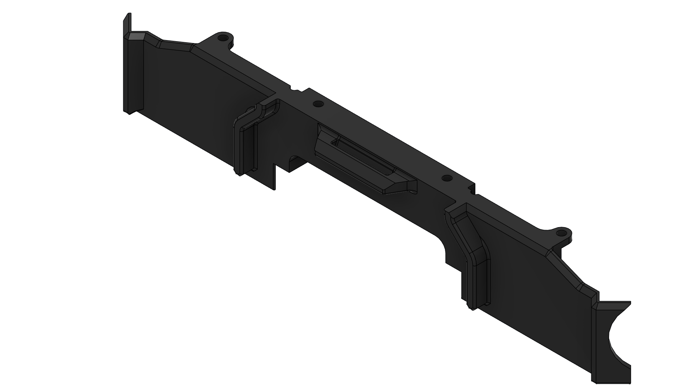
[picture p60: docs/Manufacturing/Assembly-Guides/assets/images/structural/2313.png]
| Image|  |
| CAD File|[2313](Assembly-Guides/assets/models/structural/2313.stl)|
---
### 2321 - Sensor Mount
- 3D printed.
- PETG-CF.
- Use 6 wall loops.
- Qty: 1.

| | 2321  (Sensor Mount) |
|--|--|
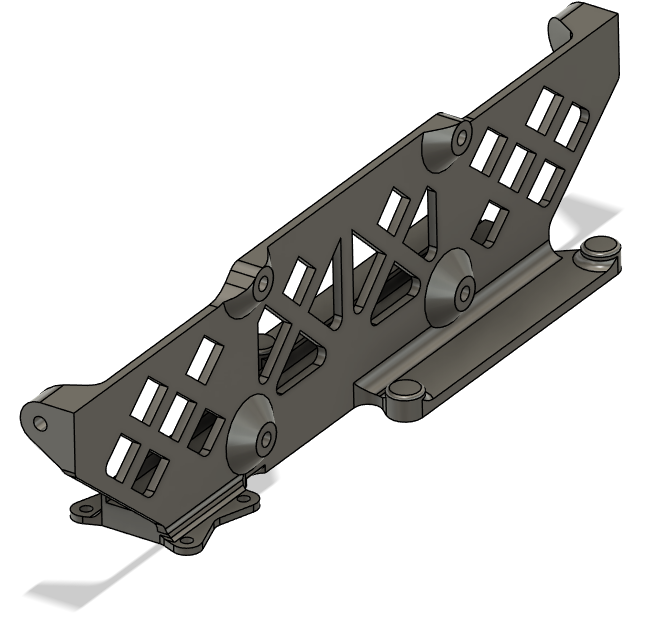
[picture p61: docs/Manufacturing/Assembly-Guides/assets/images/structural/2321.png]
| Image|  |
| CAD File|[2321](Assembly-Guides/assets/models/structural/2321.stl)|
---
### 2331 - GNSS Mount
- 3D printed.
- PETG-CF.
- Use 6 wall loops.
- Qty: 1.

| | 2331  (GNSS Mount) |
|--|--|
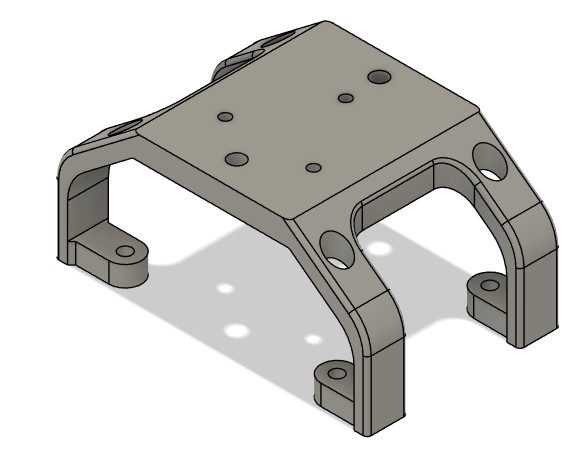
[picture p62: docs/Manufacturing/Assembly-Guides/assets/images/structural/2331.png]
| Image|  |
| CAD File|[2331](Assembly-Guides/assets/models/structural/2331.stl)|
---
### 2341 - PPP & Beacon Mount
- 3D printed.
- PETG-CF.
- Use 6 wall loops.
- Qty: 1.

| | 2341  (PPP & Beacon Mount) |
|--|--|
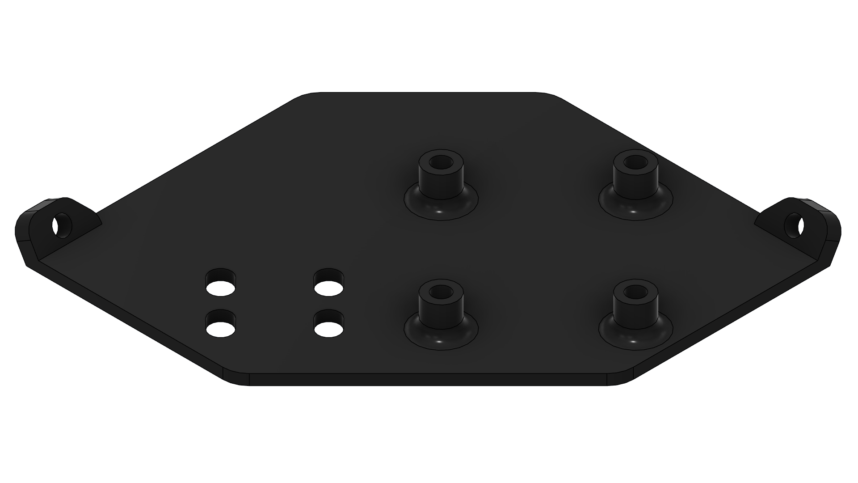
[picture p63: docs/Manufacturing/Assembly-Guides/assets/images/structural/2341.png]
| Image|  |
| CAD File|[2341](Assembly-Guides/assets/models/structural/2341.stl)|
---
### 2411 - Main Enclosure
- 3D printed.
- PETG-CF.
- Use 6 wall loops.
- Qty: 1.

| | 2411  (Main Enclosure) |
|--|--|
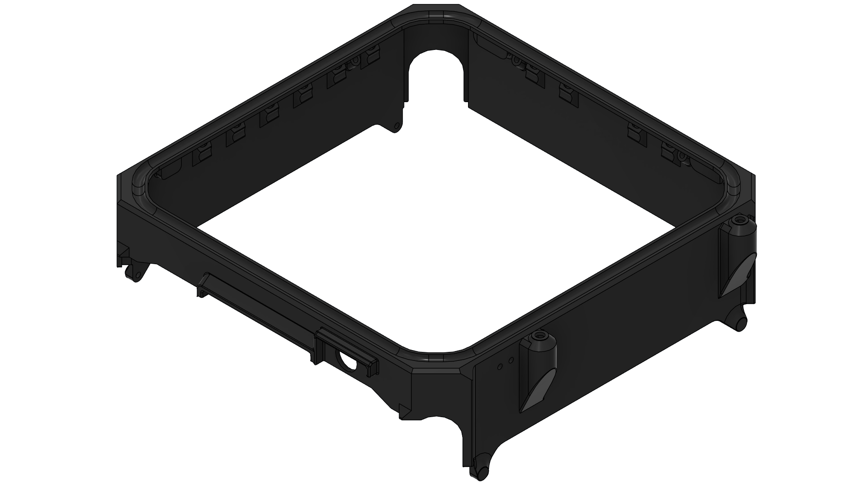
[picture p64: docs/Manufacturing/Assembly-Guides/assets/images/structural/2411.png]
| Image|  |
| CAD File|[2411](Assembly-Guides/assets/models/structural/2411.stl)|
---
### 2412 - Top Cap
- 3D printed.
- PETG-CF.
- Use 6 wall loops.
- Mind the print orientation as shown.
- Qty: 1.
---
| | 2412  (Top Cap) |
|--|--|
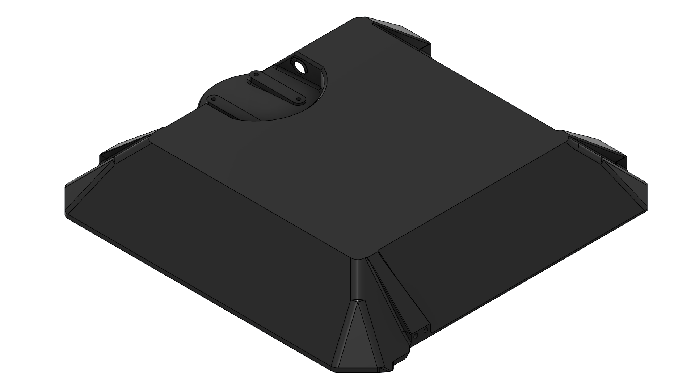
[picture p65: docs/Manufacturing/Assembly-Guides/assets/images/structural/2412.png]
| Image|  |
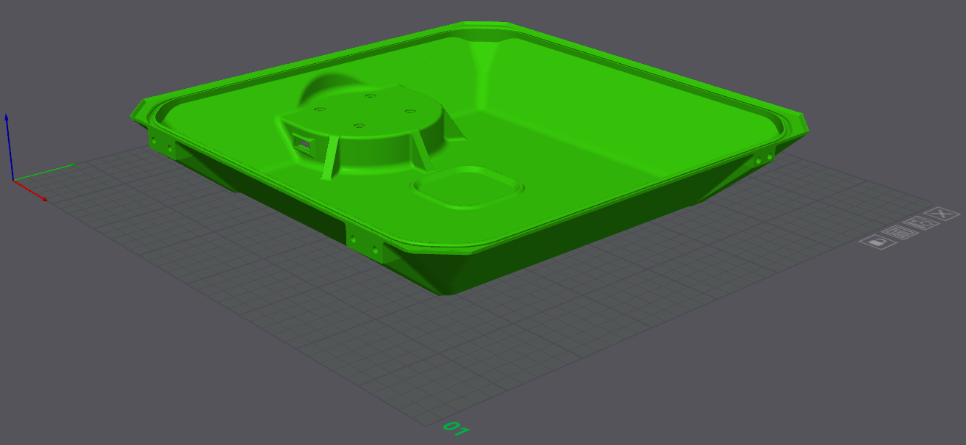
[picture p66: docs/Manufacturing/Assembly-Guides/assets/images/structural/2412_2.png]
| Print Orientation|  |
| CAD File|[2412](Assembly-Guides/assets/models/structural/2412.stl)|
---
### 2421 & 2422 - Enclosure Hinges
- Off-the-shelf component.
- Part Number: GN 237-ZD-30-30-A-SW
- Product Link: [Link](https://www.jwwinco.com/en-us/products/3.3-Hinging-latching-locking-of-doors-and-covers/Hinges/GN-237-Zinc-Die-Cast-or-Aluminum-Hinges-Countersunk-Thru-Holes-or-Thre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)
- Qty: 2.

| 2421 & 2422  (Enclosure Hinges) |
|--|
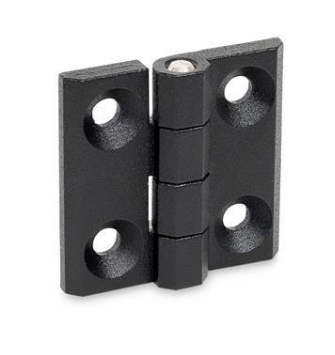
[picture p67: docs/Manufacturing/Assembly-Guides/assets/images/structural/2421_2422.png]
|  |
---
### 2431 & 2432 - Enclosure Latches
- Off-the-shelf component.
- Screw on draw latch.
- Parts are identical; Qty: 2.
- Product Link:
  - US: [Link](https://www.mcmaster.com/6082A11/)
  - UK: Latch and catch plate are sold separately.
    - [Latch](https://protex.com/21-1785SS-non-adjustable-toggle-latch-light-duty-stainless-steel-natural)
    - [Catch Plate](https://protex.com/01-1785SS-catch-plate-for-toggle-latch-stainless-steel-natural)
---
### 3322 & 3323 - Busbars
- Both are Copper C110 | CU ETP, laser cut, bent.
- Bounding box dimension is 300x300 mm for each.
- Qty: 1 each.
- Reference supplier: [Rapiddirect](https://www.rapiddirect.com/)

| | 3322 (Busbar Positive) | 3323 (Busbar Negative) |
|--|--|--|
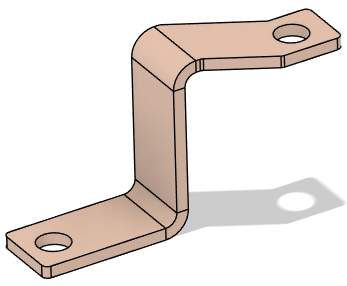
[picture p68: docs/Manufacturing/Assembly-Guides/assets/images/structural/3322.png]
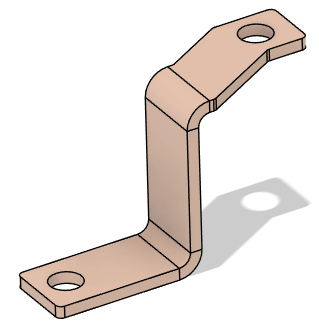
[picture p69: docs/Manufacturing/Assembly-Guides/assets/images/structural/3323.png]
| Image|  |  |
| CAD File|[3322](Assembly-Guides/assets/models/structural/3322.step)| [3323](Assembly-Guides/assets/models/structural/3323.step)|
--
### 3324 - BC PCB Heatsink
- Aluminum 6 series, laser cut, sanded.
- Experimental part:
  - Order both 4 mm and 5 mm thickness variants for evaluation.
- Qty: 1 each.
- Reference supplier: [Rapiddirect](https://www.rapiddirect.com/)

| | 3324 (BC PCB Heatsink) |
|--|--|
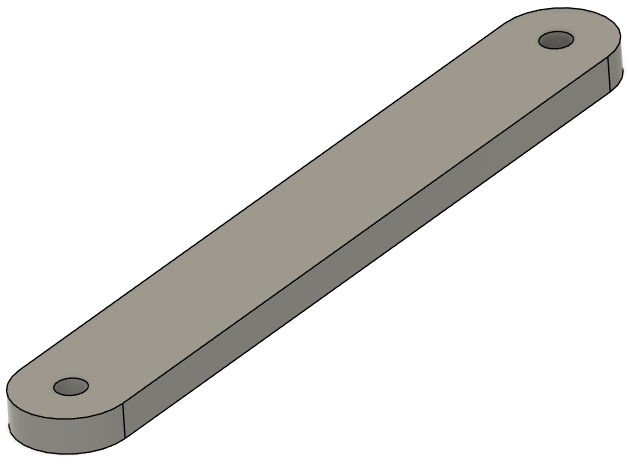
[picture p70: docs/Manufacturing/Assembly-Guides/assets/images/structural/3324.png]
| Image|  |
| CAD File|[3324 - 4 mm](Assembly-Guides/assets/models/structural/3324_1.step) , [3324 - 5 mm](Assembly-Guides/assets/models/structural/3324_2.step)|
---

## Assembly Steps

### Step 1. Assemble the Cockpit Support Beams on Mid Plate
- Parts needed:
  - 1112 (Mid Plate)
  - 1211, 1212 & 1213 (Cockpit Support Beams)
  - Rivet 1 x13 (4mm Diameter for 1 mm - 2.5 mm thickness)

- Place the cockpit support beams on the mid plate as shown in the picture.
- Rivet the cockpit support beams from the mid plate on the holes shown in the picture.

|Orientation|Rivet Holes|
|--|--|
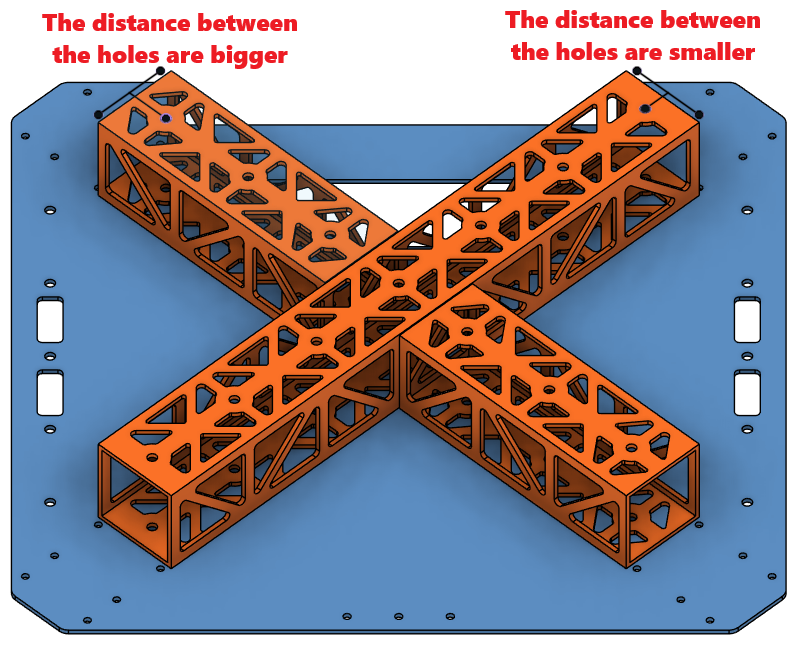
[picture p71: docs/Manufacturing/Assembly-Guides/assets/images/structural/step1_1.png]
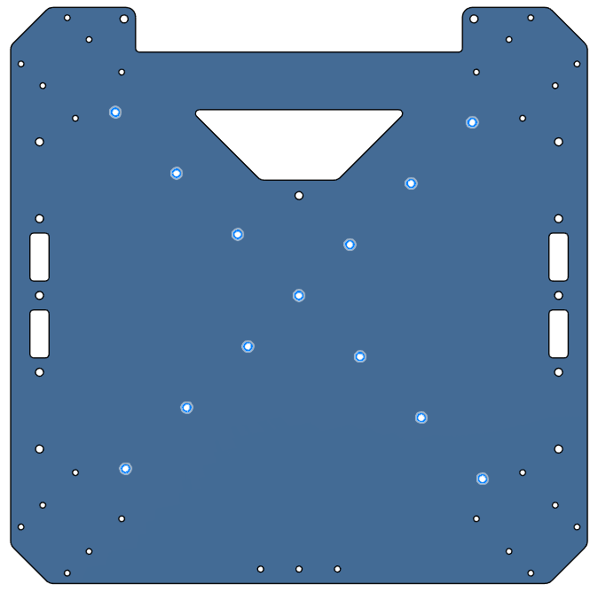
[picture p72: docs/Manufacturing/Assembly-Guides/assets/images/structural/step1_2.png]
||  |
---

### Step 2. Install the Battery Walls
- Parts needed:
  - 1221 & 1222 (Battery Walls)
  - Rivet 2 x10 (4mm Diameter for 2.5 mm - 4.5 mm thickness)
- Place the battery walls on the sides of the chassis as shown in the picture.
  - Make sure the dented side stays on the chassis side.
- Rivet the battery walls from the mid plate on the holes shown in the picture.

|Orientation|Rivet Holes|
|--|--|
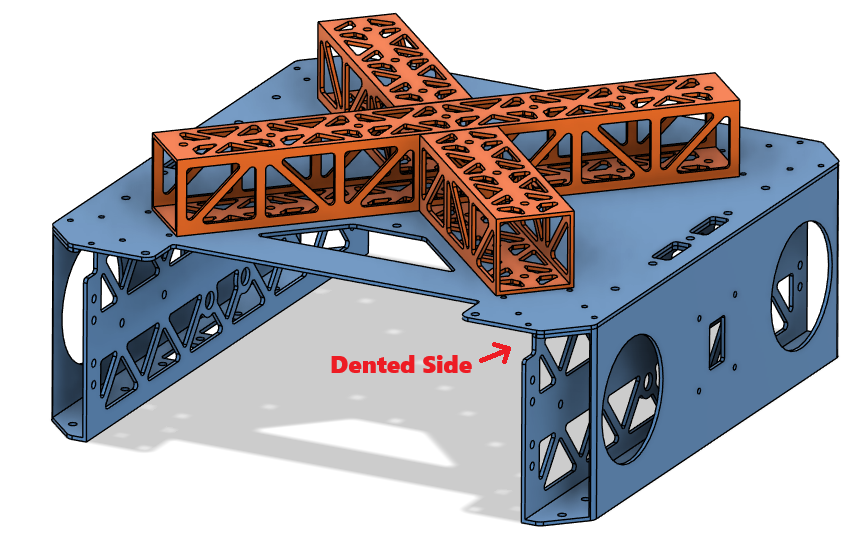
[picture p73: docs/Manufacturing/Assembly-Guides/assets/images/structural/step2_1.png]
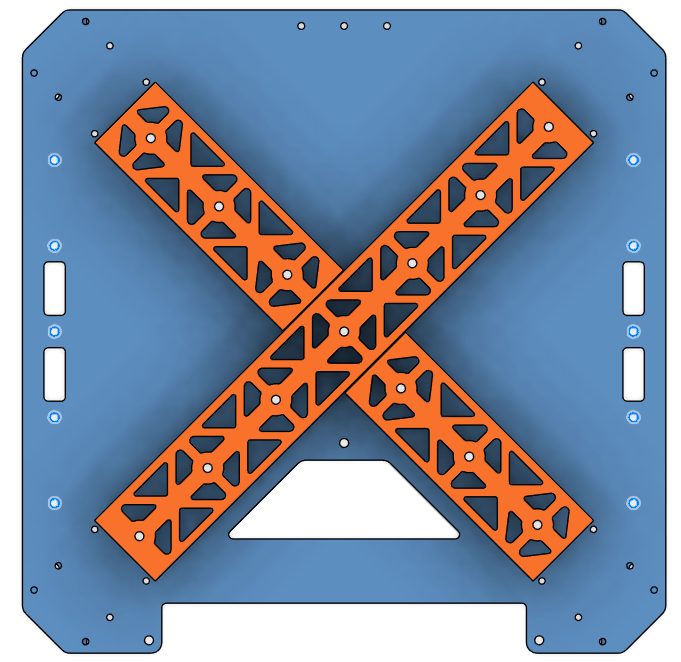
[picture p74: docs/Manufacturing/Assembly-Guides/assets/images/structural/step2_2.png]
||  |
---

### Step 3. Install the Motor Arm Connectors
- Parts needed:
  - 14X1 x4 (Foldable Motor Arm Connectors)
  - Screw 5 x16 (Socket Head Screw M3x8)
  - Screw 1 x8 (Socket Head Screw M3x10)
  - Washer 1 x24 (M3 General Purpose Washer 3.2 mm ID, 6 mm OD)
  - Loctite Threadlocker Blue 242
  - Loctite Threadlocker Red 262

- Remove the fasteners marked in the picture.
  - Apply Loctite Threadlocker Red on the fasteners.
  - Secure the fasteners back.

| Motor Arm Connector - Loctite Threadlocker Application|
|---|
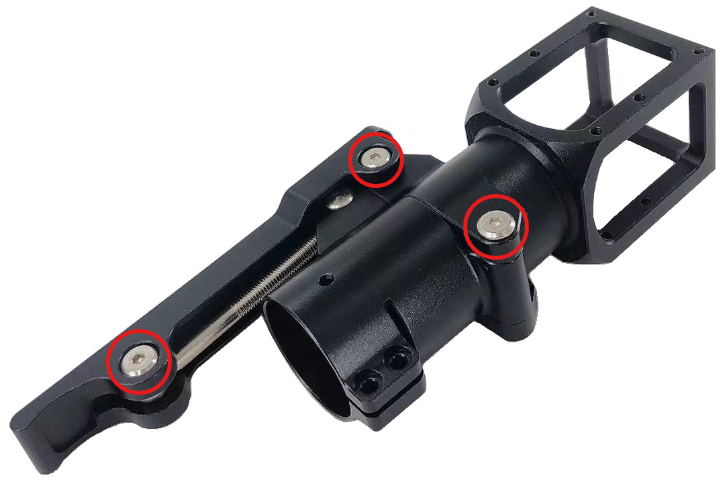
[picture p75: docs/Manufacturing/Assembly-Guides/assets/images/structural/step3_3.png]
| |

- Place the motor arm connectors on the chassis as shown in the picture.
- Secure the motor arm connectors on the chassis.
  - Use **Screw 5** for **red holes** and **Screw 1** for **green holes**.
  - Use Loctite Threadlocker Blue.
  - Use Washer 1.
  - Use cordless screwdriver where possible, or else an allen key.

|Orientation|Screw Holes|
|--|--|
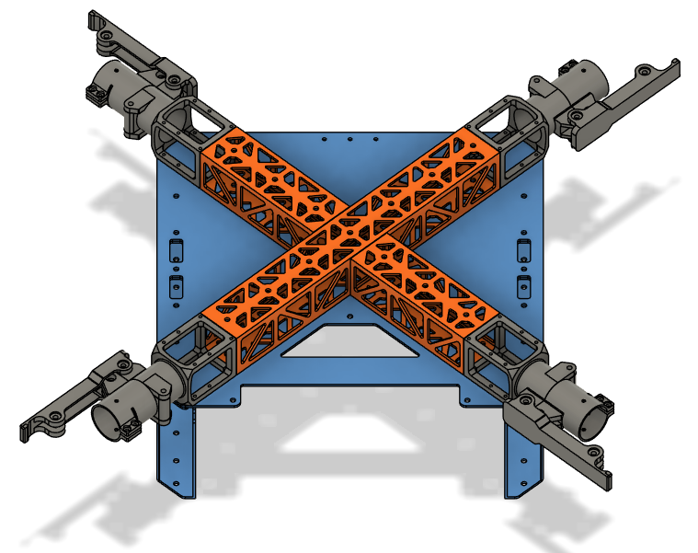
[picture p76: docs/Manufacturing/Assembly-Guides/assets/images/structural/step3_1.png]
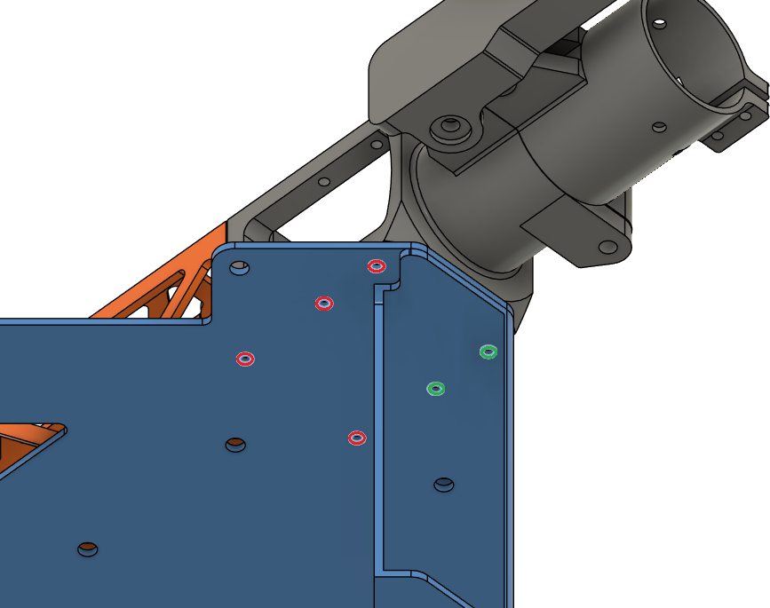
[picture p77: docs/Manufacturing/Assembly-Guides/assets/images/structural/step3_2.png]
||  |
---
### Step 4. Install the Lower Plate
- Parts needed:
  - 1113 (Lower Plate)
  - Rivet 3 x10 (4mm Diameter for 4.5 mm - 6.4 mm thickness)
- Place the lower plate on the chassis as shown in the picture.
- Rivet the lower plate to the chassis on the holes shown in the picture.

|Orientation|Rivet Holes|
|--|--|
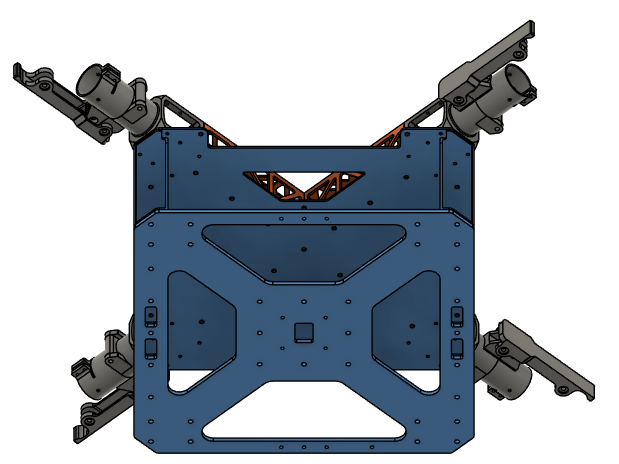
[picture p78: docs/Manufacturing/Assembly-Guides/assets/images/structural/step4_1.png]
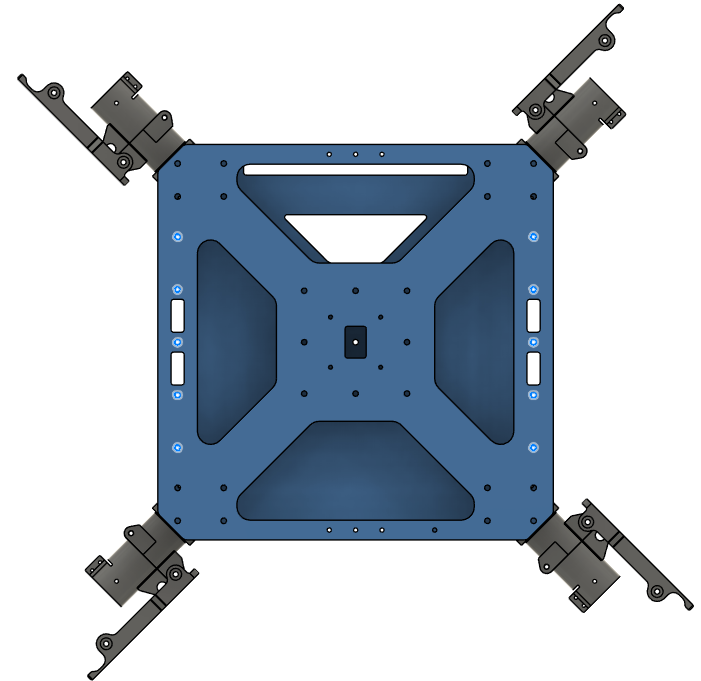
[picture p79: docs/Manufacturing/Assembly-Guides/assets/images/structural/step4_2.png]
||  |
---
### Step 5. Install the Upper Plate
- Parts needed:
  - 1111 (Upper Plate)
  - Rivet 1 x13 (4mm Diameter for 1 mm - 2.5 mm thickness)
  - Screw 5 x24 (Socket Head Screw M3x8)
  - Washer 1 x24 (M3 General Purpose Washer 3.2 mm ID, 6 mm OD)
  - Loctite Threadlocker Blue 242

- Place the upper plate over the chassis as shown in the picture.
- Rivet the cockpit support beams from the upper plate on the holes shown in the picture.
- Screw the motor arm connectors from the upper plate with Screw 5.
  - Use Washer 1.
  - Use Loctite Threadlocker Blue.

|Orientation|Rivet Holes|
|--|--|
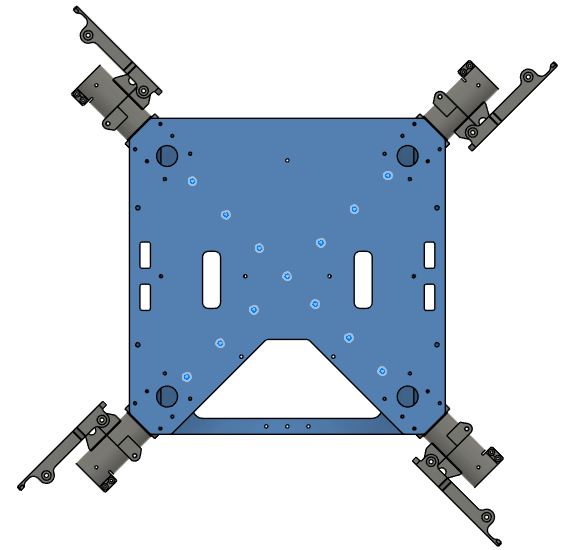
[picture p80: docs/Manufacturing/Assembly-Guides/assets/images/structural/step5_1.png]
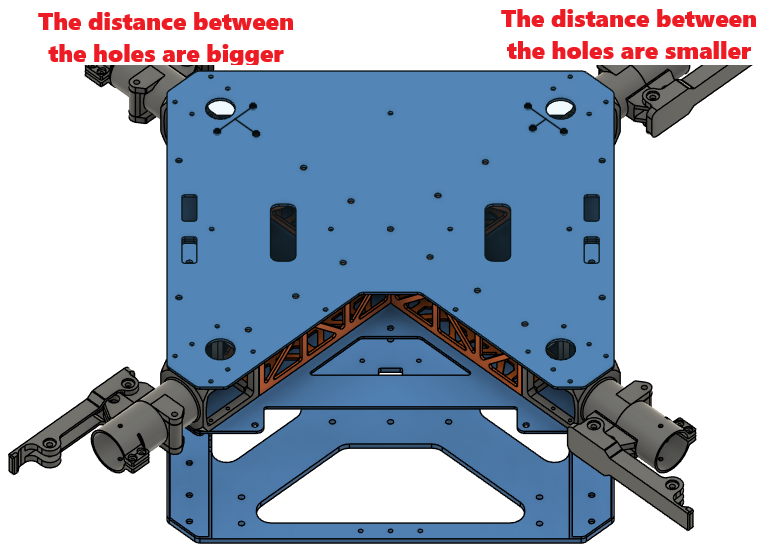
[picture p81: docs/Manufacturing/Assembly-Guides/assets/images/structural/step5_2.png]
||  |
---
### Step 6. Install the Main PCB Mount
- Parts needed:
  - 2311 (Main PCB Mount)
  - Screw 11 x5 (Flanged Button Head Hex-Drive Screw M3x6)
  - Vibration Mount x5 (M3 Rubber Anti-Vibration Spacer)
  - Insert 4 x16 (M3 Threaded Inserts - 3.8 mm)
  - Loctite Threadlocker Blue 242

- Install 11x Insert 4 into the top face of the Main PCB Mount as shown in the picture.

| Top Insert Locations|
|---|
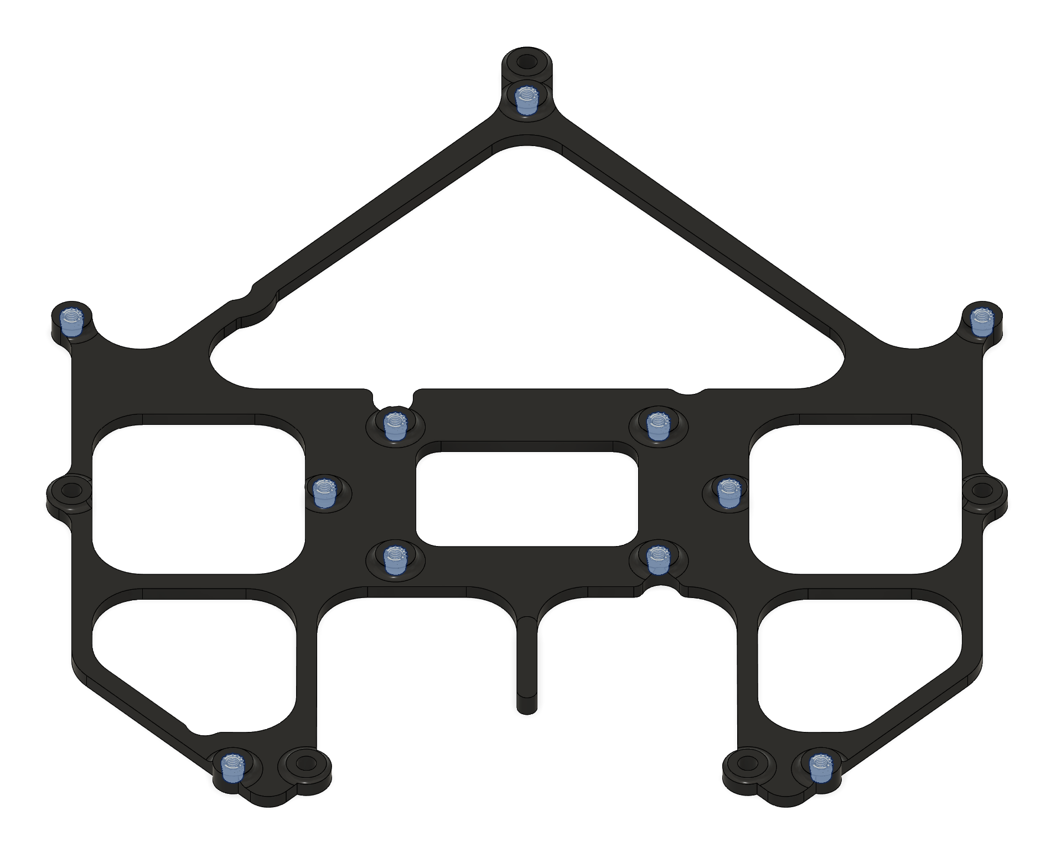
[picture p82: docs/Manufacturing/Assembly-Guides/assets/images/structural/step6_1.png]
| |

- Install 5x Insert 4 into the bottom face of the Main PCB Mount (2311) as shown in the picture.

| Bottom Insert Locations|
|---|
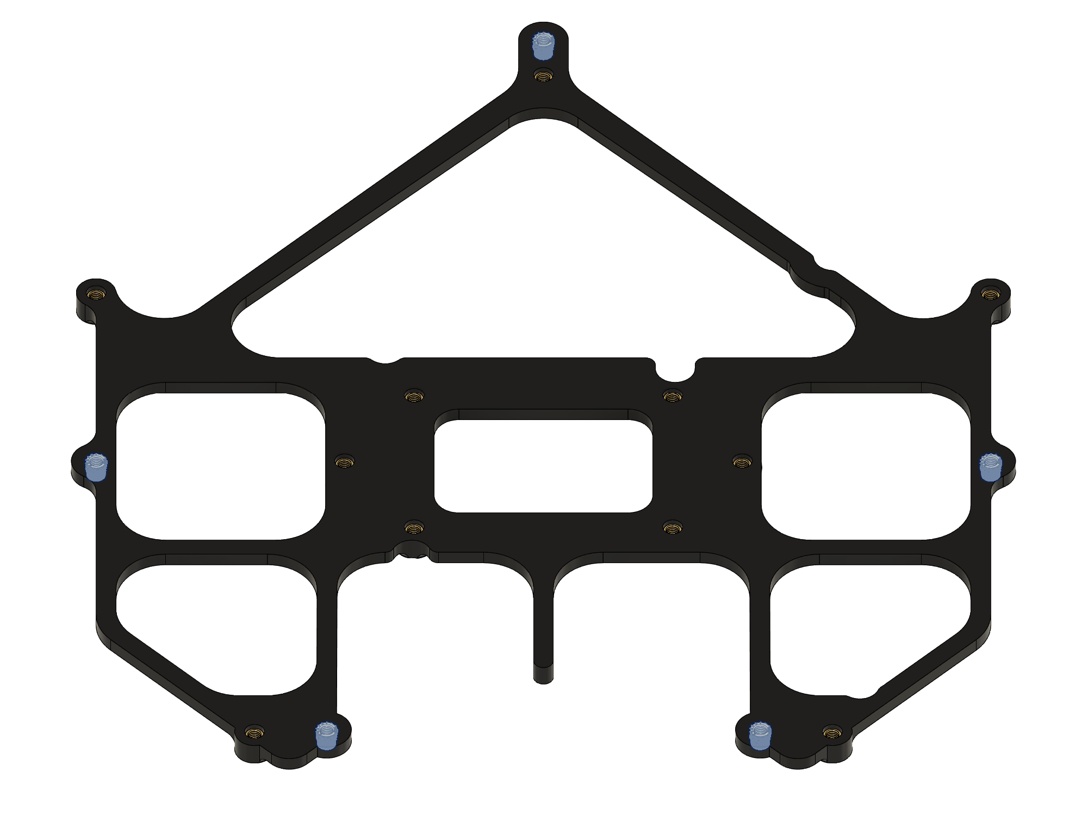
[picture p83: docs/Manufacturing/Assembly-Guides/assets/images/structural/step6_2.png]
| |

- Install 5x Vibration Mount into the designated holes on the Upper Plate (1111).
- Orientation: Ensure the longer side of the rubber dampener (3 mm section) is facing upwards, towards where the 3D-printed holder will sit.

| Vibration Mount Locations| Vibration Mount Insertion |
|---|---|
| | |

- Apply a small amount of Loctite Threadlocker Blue to the threads of the 5x Screw 11 (M3x6) flat head screws.
- Align the 3D-printed mount over the rubber dampeners.
- Insert the Screw 11 (M3x6) screws through the center of the rubber dampeners and thread them into the bottom-side inserts of the PCB holder.
- **Compression:** Tighten the screws until the rubber dampener is compressed to a height of approximately **2.0 mm**. Refer to the visual guide below.

| Vibration Mount Compression|
|---|
| |
---
### Step 7. Install the Battery Connector PCB Mount
- Parts needed:
  - 2312 (BC PCB Mount)
  - Insert 1 x10 (M3 Threaded Inserts - 5.7 mm)
  - Screw 5 x3 (Socket Head Screw M3x8)
  - Washer 1 x3 (M3 General Purpose Washer 3.2 mm ID, 6 mm OD)

- Place Insert 1 to the holes shown in the picture, on the top and bottom sides of the BC PCB mount.
  - Use a soldering iron to place them inside the plastic.

|Top|Bottom|
|--|--|
||  |

- Place the Battery Connector PCB mount over the mid plate.
  - Secure it with 3x Screw 5 in total from below the mid plate on the holes below.
  - Use Washer 1 for the holes.



---

### Step 8. Install the Battery Sliders
- Parts needed:
  - 2211, 2212 (Battery Sliders)
  - Insert 2 x8 (M4 Threaded Inserts)
  - Screw 9 x8 (Socket Head Screw M4x8)
  - Washer 2 x8 (M4 General Purpose Washer 4.3 mm ID, 9 mm OD)

- Place Insert 2 to the holes shown in the picture on both of the battery slides.
  - Use a soldering iron to place them inside the plastic.



- Place the battery sliders inside the battery compartment.
  - Be careful about the orientation of the angled end, they should point where the cutouts on the plates are.
  - Secure it with 8x Screw 9 in total from the sides of the frame.
  - Use Washer 2 with the screws.

|Orientation|Installation Holes|
|--|--|
||  |
---
### Step 9. Install the Landing Gear
- Parts needed:
  - 131X, 132X (Landing Gear Horizontal & Vertical Tubes)
  - 133X (Landing Gear Main Adapters)
  - 134X (Landing Gear Tube Joints)
  - 135X (Landing Gear Foam)
  - Screw 2 x16 (Flanged Button Head Screw M4x10)
  - Screw 5 x16 (Socket Head Screw M3x8)
  - Washer 1 x16 (M3 General Purpose Washer 3.2 mm ID, 6 mm OD)
  - Loctite Threadlocker Blue 242
  - Loctite Threadlocker Purple 222

- Place the landing gear main adapters below the chassis, as shown in the picture.
  -  The adapters are facing outward, to the left and right of the structure.
  -  Screw the adapters with 16x Screw 2 to the chassis.
  -  Use Loctite Threadlocker Blue to secure the screws.

|Orientation|Installation Holes|
|--|--|
||  |

- Insert the vertical landing gear tubes inside landing gear main adapters.
  - Make sure the tubes are inserted all the way.
  - Tighten the clamps to secure the tubes in place.

:::note

Due to the lack of the detachable landing gear adapter geometry, this image depicts the old adapter. It should be updated with a real life image.
:::

|Landing Gear Adapter|
|---|
||

- Make sure the chassis stands level on the ground.
  -  If not, measure and equalize the tube lengths.

- Assemble landing gear tube joints and the horizontal tubes as shown in the picture.
  - Insert the vertical tubes inside the holes before tightening the screws.
  - Use Screw 5.
  - Use Washer 1.
  - Use Loctite Threadlocker Purple.

|Positioning|Correct Final Appearance |
|--|--|
||  |

:::note

Due to the lack of the landing gear tee joint geometry, this image depicts the old joint. It should be updated with a real life image.
:::

- Slide the landing gear foams to the end of the horizontal tubes.

### Step 10. Install Sensor Mount
- Parts needed:
  - 2321 (Sensor Mount)
  - Insert 1 x10 (M3 Threaded Inserts - 5.7 mm)
  - Screw 4 x4 (Socket Head Screw M3x12)
  - Screw 5 x2 (Socket Head Screw M3x8)
  - Washer 1 x6 (M3 General Purpose Washer 3.2 mm ID, 6 mm OD)
  - Nut 1 x4 (Nylon-Insert Locknut M3)
  - Loctite Threadlocker Purple 222

- Place Insert 1 to the holes shown in the picture.
  - Use a soldering iron to place them inside the plastic.
  - 10 in total.

|Insert 1 (5.7 mm) Locations|
|---|
||
||

- Secure the sensor mount on the lower plate.
  - Screw head stays inside the mount.
  - Use Screw 4.
  - Use Washer 1 on the nut side.
  - Use Nut 1.
  - DO NOT use Loctite Threadlocker.

|Lower Plate Fasteners|
|---|
||

- Secure the sensor mount on the battery walls.
  - Use Screw 5.
  - Use Washer 1.
  - Use Loctite Threadlocker Purple.

|Battery Wall Fasteners|
|---|
||
---

### Step 11. Insert Grommets
- Parts needed:
  - Grommet 1 x4 (Circular Grommet OD: 20 mm)
  - Grommet 2 x12 (Oval Grommet 27x13 mm)

- Insert 4x Grommet 1 into the holes over the motor arm connectors at each corner.

|Grommet 1 Location|
|---|
||

- Insert 12x Grommet 2 into the holes on the sides of upper, mid and lower plates on each side.

|Grommet 2 Location|
|---|
||

### Step 12. Install PCBs & Onboard Components
- Parts needed:
  - 2331 (GNSS Mount)
  - 3311 (Main PCB)
  - 3321 (BC PCB)
  - 3331 (FC PCB)
  - 3332 (Flight Controller)
  - 3312 (RPI 5)
  - 3313 x2 (GigaBlox Nano Ethernet Switch)
  - 3315 (Mateksys GNSS M9N-G4-3100)
  - 3251 (RTK GNSS)
  - Screw 4 x4 (Socket Head Screw M3x12)
  - Screw 11 x14 (Flanged Button Head Hex-Drive Screw M3x6)
  - Screw 12 x4 (Socket Head Hex-Drive Screw M2x5)
  - Screw 13 x4 (Socket Head Hex-Drive Screw M2.5x8)
  - Screw 14 x4 (Socket Head Hex-Drive Screw M2x10)
  - Washer 3 x12 (M2 Nylon Washer 2.2 mm ID, 5 mm OD)
  - Washer 4 x4 (M2.5 Nylon Washer 2.7 mm ID, 5.6 mm OD)
  - Washer 5 x4 (M3 Nylon Washer 3.2 mm ID, 6 mm OD)
  - Loctite Threadlocker Purple 222
  - Loctite Threadlocker Blue 242

- Place the Battery Connector PCB as shown in the picture.
  - Apply Thermal Paste to the Heatsink.
  - Secure it with 3x Screw 11.

|BC PCB & Bolt Locations|
|---|
||

- Place the Main PCB as shown in the picture.
  - See the warning before installation.
  - Secure it with 7x Screw 11.

:::caution
**CRITICAL: Trim DC-DC Converter Pins**

Before mounting the Main PCB, the through-hole pins of the DC-DC converters **must** be trimmed on the underside of the board. They extend too far and may puncture the mount or short against the frame.
See the reference image for the required clearance.
:::

|Main PCB & Bolt Locations| Through-hole Pin Trim|
|---|---|
|||

- Place Ethernet Switches on the Main PCB slots, as shown in the picture.
  - Securely plug the connectors.
  - Use 4x Screw 12 and 4x Washer 3 on the bolt holes.
    - Use Loctite Threadlocker Purple.

|Ethernet Switch Locations|
|--|
||

- Place the Flight Controller on the FC PCB.
  - Pay extreme attention to the orientation shown in the images.
  - Make sure the connectors are securely connected.
  - Use 4x Screw 12 and 4x Washer 3 from under the PCB to secure the Flight Controller.
    - Use Loctite Threadlocker Purple.

|FC & FC PCB Orientation ||
|--|--|
|||

- Place F9P NEO RTK GNSS on the GNSS Mount.
  - The direction of the arrow on the RTK GNSS should match the one provided in the picture.
  - Secure it with Screw 14 and Washer 3 under the mount.
    - Use Loctite Threadlocker Purple.

|GNSS Orientation|
|--|
||

- Place the FC PCB into the GNSS Mount.
- Place the FC PCB and GNSS Mount on the Main PCB.
  - The arrow on the Flight Controller must point toward the front of the drone, i.e., opposite to the side where the BC PCB is located.
  - The arrow on the RTK GNSS must point toward the front of the drone, i.e., opposite to the side where the BC PCB is located.
- Secure the FC PCB on the Main PCB using the holes shown in the image.
  - Use 4x Screw 4 and 4x Washer 5.
  - Use Loctite Threadlocker Purple.

|Flight Controller Orientation | GNSS Mount Orientation | Installation Holes |
|--|--|--|
||  | 

- Place RPI 5 on the Main PCB slot, as shown in the picture.
  - Securely plug the connectors.
  - Use 4x Screw 13 and 4x Washer 4 on the bolt holes.

|RPI 5 Installation|
|--|
||

- Place Mateksys GNSS on the Main PCB slot, as shown in the picture.
  - Securely plug the connectors.
  - Use 4x Screw 11.
    - Use Loctite Threadlocker Blue.

|Mateksys GNSS Installation|
|--|
||

#### Harness Routing Notes

Route the PCB interconnect and navigation harnesses after the BC PCB, Main PCB, FC PCB, GNSS, and onboard components are mounted.

| Harness | Source | Destination | Routing notes |
| :--- | :--- | :--- | :--- |
| HAR-0002 BC_PCB Signal | Bat_PCB J2 | Main_PCB J43 | Direct PCB interconnect. No special constraint or fixing noted. |
| HAR-0003 BC_PCB SSR | Bat_PCB J3 | Main_PCB J46 | Direct PCB interconnect. No special routing constraints currently noted. |
| HAR-0021 / HAR-0022 Navigation | Main_PCB J7, J9 | F9P/Here 4, Mateksys | Route immediately to the right. No special constraint or fixing noted. |

| HAR-0002 BC PCB Signal | HAR-0003 BC PCB SSR | HAR-0022 Navigation |
| :---: | :---: | :---: |
| HAR-0002 BC PCB signal routing | HAR-0003 BC PCB SSR routing | HAR-0022 navigation routing |

---
### Step 13. Install Busbars
- Parts needed:
  - 3322 (Busbar Positive)
  - 3323 (Busbar Negative)
  - Screw 15 x4 (Socket Head Hex-Drive Screw M5x8)
  - Washer 6 x4 (M5 General Purpose Washer 5.3 mm ID, 10 mm OD)
  - Loctite Threadlocker Blue 242

- Place the Busbar Positive (Right) and Busbar Negative (Left) on the Main and BC PCBs as shown in the picture.
  - Use Loctite Threadlocker Blue on the threads of 4x Screw 15.
  - Secure the busbars on the terminals with Screw 15 and Washer 6.

|Busbar Installation|
|--|
||

---
### Step 14. Install BC PCB Cover
- Parts needed:
  - 2313 (BC PCB Cover)
  - Insert 1 x2 (M3 Threaded Inserts - 5.7 mm)
  - Screw 5 x4 (Socket Head Screw M3x8)
  - Washer 1 x4 (M3 General Purpose Washer 3.2 mm ID, 6 mm OD)
  - Loctite Threadlocker Purple 222

- Place Insert 1 to the holes shown in the picture.
  - Use a soldering iron to place them inside the plastic.
  - 2 in total.

- Use Screw 5 and Washer 1 to secure the BC PCB Cover in place.
  - Use Loctite Threadlocker Purple.

| Insert 1 Locations | Screw Locations |
|--|--|
|||

---
### Step 15. Install Attachment Interfaces
- Parts needed:
  - 2111, 2121 & 2131 (Attachment Interface Spacers)
  - 2112, 2122 & 2132 (Attachment Interfaces)
  - Screw 6 x8 (Socket Head Screw M3x40)
  - Screw 16 x4 (Button Head Hex Drive Screw M3x40)
  - Washer 1 x12 (M3 General Purpose Washer 3.2 mm ID, 6 mm OD)
  - Loctite Threadlocker Blue 242

- Place and secure the side attachment interfaces and the spacers as shown in the pictures.
  - Make sure the rectangular holes are aligned with the holes on the battery walls.
  - Make sure the notch on the attachment interface is on top, as shown in the image.
  - Use the screwdriver holes inside the battery compartment to place the screws and the screwdriver.
  - Use 8x Screw 6.
  - Use 8x Washer 1.
  - Use Loctite Threadlocker Blue.

|Positioning|Installation Holes| Notch Orientation|
|--|--|--|
||  |  |

- Place and secure the bottom attachment interface and the spacer as shown in the pictures.
  - Make sure the rectangular holes are aligned with the holes on the battery walls.
  - Make sure the cable tray on the spacer points towards the front, i.e. the sensor mount.
  - Make sure the notch on the attachment interface points towards the front, i.e. the sensor mount.
  - Use 4x Screw 16.
  - Use 4x Washer 1.
  - Use Loctite Threadlocker Blue.

|Positioning, Cable & Notch Orientation|Installation Holes|
|--|--|
||  |
---
### Step 16. Install Radar Sensors
- Parts needed:
  - 3212 (Obstacle Avoidance Radar, Nanoradar MR82)
  - 3213 (Radar Altimeter, Nanoradar NRA15)
  - Screw 5 x4 (Socket Head Screw M3x8)
  - Screw 11 x4 (Flanged Button Head Hex-Drive Screw M3x6)
  - Loctite Threadlocker Purple 222

- Secure Nanoradar MR82 in front of the drone, as shown in the image.
  - Use 4x Screw 11.
  - Use Loctite Threadlocker Purple.
  - Mind the direction of the cable.

|Obstacle Avoidance Installation|
|--|
||

- Secure Nanoradar NRA15 in front-bottom corner of the drone, as shown in the image.
  - Use 4x Screw 5.
  - Use Loctite Threadlocker Purple.
  - Mind the direction of the cable.

|Radar Altimeter Installation|
|--|
||

#### Harness Routing Notes

Route radar and altimeter harnesses while installing the sensors.

| Harness | Source | Destination | Routing notes |
| :--- | :--- | :--- | :--- |
| HAR-0015 Altimeter | Main PCB J8 | NRA15 | Route from the right-side top-plate entry to the bottom plate. Watch other cables and fix with the marked zip tie. |
| HAR-0017 Front Radar | Main PCB J49 | Front radar | Route from the right-side top-plate entry to the bottom plate. Watch other cables and fix with the marked zip tie. |

| HAR-0015 Altimeter — View 1 | HAR-0015 Altimeter — View 2 |
| :---: | :---: |
| HAR-0015 altimeter routing 1 | HAR-0015 altimeter routing 2 |
| HAR-0017 Front Radar — View 1 | HAR-0017 Front Radar — View 2 |
| HAR-0017 front radar routing 1 | HAR-0017 front radar routing 2 |

---
### Step 17. Install Camera
- Parts needed:
  - 3241 (SIYI A8 Mini Gimbal Camera)
  - Screw 7 x4 (Socket Head Screw M2.5x6)
  - Washer 4 x4 (M2.5 Nylon Washer 2.7 mm ID, 5.6 mm OD)
  - Insert 5 x4 (M2.5 Threaded Inserts)
  - Loctite Threadlocker Purple 222

- Install 4x Insert 5 into the camera mounting holes on the drone.
- Secure SIYI A8 Mini Gimbal Camera in front-bottom corner of the drone, as shown in the image.
  - Use 4x Screw 7.
  - Use 4x Washer 4.
  - Use Loctite Threadlocker Purple.
  - Mind the orientation of the camera, make sure the gimbal center points forward, i.e. away from the drone.

| Camera Installation Holes | Camera Orientation |
|--|--|
|||

#### Harness Routing Notes

Route the camera harness while installing the SIYI camera.

| Harness | Source | Destination | Routing notes |
| :--- | :--- | :--- | :--- |
| HAR-0027 SIYI Camera | HM30 LAN and power | SIYI A8 | Route through the right-side middle-plate opening to the underside of the bottom plate. Watch other cables and use zip ties as needed. |

| HAR-0027 SIYI Camera — View 1 | HAR-0027 SIYI Camera — View 2 |
| :---: | :---: |
| HAR-0027 SIYI camera routing 1 | HAR-0027 SIYI camera routing 2 |

---
### Step 18. Install Motor Arm Tubes & Motors
- Parts needed:
  - 14X2 (4x Motor Arm Tubes)
  - 31X1 (4x Hobbywing X6 Plus Motors)
  - Screw 6 x8
  - Washer 1 x16
  - Nut 1 x8
  - Loctite Threadlocker Blue 242

- Drill holes on the motor arm tubes for assembly.
  - Pay close attention to hole alignment. Both longitudinal (axial) and radial (rotational) alignment must be maintained.
  - See the image for distancing.
  - Use 3 mm drill bit.
  - This step is critical. Improper hole alignment may result in thrust imbalance.
    - A drill jig may be used to ensure proper alignment.

|Motor Arm Tube Hole Drilling Layout|
|--|
||

- Slide a tube inside each motor tube clamp.
  - Orient the tube so that the motor is installed on the end with the shorter hole-to-end distance.
  - Route the motor & ESC cables through the inside of the tube.
  - Make sure the tubes are inserted all the way.
  - Use Screw 6 to fix the tube in place.
  - Use Washer 1 on each side.
  - Use Nut 1.
  - Do not apply more than 0.6 Nm of torque.

- Tighten the clamps with the screws provided in the motor package.
- Use Loctite Threadlocker Blue to secure the screws.

|Motor Installation|
|--|
||

- Install the motor arms on the motor arm connectors.
  - Mind the motor spin directions. Use **Ardupilot Quad X** motor layout. See the image for reference. The front of the drone is where the radar sensors are.
  - Make sure the tubes are inserted all the way.
  - Route the cables from inside the tube, through the cable exit hole on top of the motor arm connector.
  - Use Screw 6 to fix the tube in place.
  - Use Washer 1 on each side.
  - Use Nut 1.
  - Do not apply more than 0.6 Nm of torque.

- Tighten the clamps with the screws provided in the motor arm connector package.
- Use Loctite Threadlocker Blue to secure the screws.

|Motor Arm Installation| Motor Cable Routing|
|--|--|
|||

- Set the LED colors at each end of the motors.
  - LEDs on the left side motors (Motors 2 & 3, C & D) should be **RED**.
  - LEDs on the right side motors (Motors 1 & 4, A & B) should be **GREEN**.
  - Use the [motor user manual](https://www.hobbywing.com/en/uploads/file/20230530/4b6e40b9a412b8675f68c065aece5644.pdf) to set the colors.

|Adjusting LED Color Instructions|
|--|
||

#### Harness Routing Notes

Route motor/ESC harnesses with the motor arms.

| Harness | Source | Destination | Routing notes |
| :--- | :--- | :--- | :--- |
| HAR-0004 / HAR-0005 / HAR-0006 / HAR-0007 ESC Power | Main_PCB J27 | ESC power leads | Route through the circular hole on the upper plate to the middle plate. No special constraint or fixing noted. |
| HAR-0008 / HAR-0009 / HAR-0010 / HAR-0011 ESC Signal | Bat_PCB J2 | Main_PCB J43 | No special routing constraint or fixing currently noted. |

| HAR-0004 ESC Power | HAR-0008 ESC Signal |
| :---: | :---: |
| HAR-0004 ESC power routing | HAR-0008 ESC signal routing |

---

### Step 19. Install Telemetry Air Unit & Attachment Interface PCBs
- Parts needed:
  - 3223 (HM30 Telemetry Air Unit)
  - 3341, 3342, 3343 (Attachment Interface PCBs)
  - Screw 3 x12 (Button Head Hex-Drive Screw M2x4)
  - Loctite Threadlocker Purple 222
  - Double-Sided Tape

- Install the HM30 air unit on the right side of the drone.
  - Secure tightly with double-sided tape.
  - Mind the orientation.

|HM30 Air Unit installation|
|--|
||

- Install the attachment interface PCBs on all three attachment interfaces.
  - The pin side will face outward, while the connector side will stay inside.
  - Make sure the side with the notch mark will be on the notch side of the attachment interface. (See Step 15 for notch reference)
  - Secure them with Screw 3.
    - Use Loctite Threadlocker Purple.

|Attachment Interface PCB Orientation| PCB Location |
|--|--|
|||

#### Harness Routing Notes

Route HM30 and attachment-interface harnesses while installing the telemetry air unit and attachment interface PCBs.

| Harness | Source | Destination | Routing notes |
| :--- | :--- | :--- | :--- |
| HAR-0018 HM30 Power | Main_PCB J27 | HM30 power | Route through the right-side top-plate opening. No special constraint or fixing noted. |
| HAR-0019 / HAR-0020 HM30 Signal | Bat_PCB J15, J17 | HM30 | Route through the right-side top-plate opening. Watch other cables and secure with zip ties. |
| HAR-0012 / HAR-0013 Side Payloads | Main_PCB J29, J37 | ATT_INT right/left | Route underneath the Main PCB to the middle-plate side circular openings. Mirror the path for the opposite side. Watch the telemetry air unit location. |
| HAR-0014 Bottom Payload | Main_PCB J31, J39 | ATT_INT bottom | Route from the top plate through the right-side opening and mid-plate openings, then attach to the underside of the bottom plate. Watch the number of cables passing through openings. Fix with zip ties at the marked locations. |

| HAR-0018 HM30 Power | HAR-0019 HM30 Signal — View 1 |
| :---: | :---: |
| HAR-0018 HM30 power routing | HAR-0019 HM30 signal routing 1 |
| HAR-0019 HM30 Signal — View 2 | HAR-0020 HM30 Signal |
| HAR-0019 HM30 signal routing 2 | HAR-0020 HM30 signal routing |

| HAR-0012 Side Payload | HAR-0014 Bottom Payload — View 1 | HAR-0014 Bottom Payload — View 2 |
| :---: | :---: | :---: |
| HAR-0012 side payload routing | HAR-0014 bottom payload routing 1 | HAR-0014 bottom payload routing 2 |

---

### Step 20. Install Main Enclosure & Top Cap
- Parts needed:
  - 2411 (Main Enclosure)
  - 2412 (Top Cap)
  - 2421 & 2422 (Enclosure Hinges)
  - 2431 & 2432 (Enclosure Latches)
  - Insert 1 x28 (M3 Threaded Inserts - 5.7 mm)
  - Silicone Foam Seal Strip (OD: 8 mm)
  - Screw 5 x4 (Socket Head Screw M3x8)
  - Screw 8 x8 (Hex Drive Flat Head Screw M3x10)
  - Screw 17 x8 (Socket Head Screw M3x6)
  - Washer 1 x4 (M3 General Purpose Washer 3.2 mm ID, 6 mm OD)
  - Loctite Threadlocker Purple 222
  - Würth Super RTV Silicone Black

- Place Insert 1 to the holes shown in the picture on the main enclosure.
  - Use a soldering iron to place them inside the plastic.
  - 16 in total.

|Insert 1 (5.7 mm) Locations|
|---|
||

- Place Insert 1 to the holes shown in the picture on the top cap.
  - Use a soldering iron to place them inside the plastic.
  - 12 in total.

|Insert 1 (5.7 mm) Locations|
|---|
||

- Place Silicone Foam Seal Strip in the groove on the main enclosure.
  - Cut the seal strip to length that minimizes the gap between the ends.
  - Use Würth Super RTV Silicone Black to install it in the groove.
  - Seal the gap between the ends of the strip with Würth Super RTV Silicone Black.

|Silicone Foam Seal Strip Location|
|---|
||

- Install the hinges and latches on the main enclosure and the top cap.
  - Use Screw 8 for the hinges.
  - Use Screw 17 for the latches.
  - Use Loctite Threadlocker Purple.

|Hinge & Latch Installation|
|---|
||

- Place the main enclosure and the top cap on the aircraft.
  - Apply Würth Super RTV Silicone Black on the contact surface between the BC-PCB cover and the main enclosure, as shown in the image.
  - Make sure the antenna cables stay over the upper plate, as they will be hard to grab afterwards.

|Würth Super RTV Silicone Black Application|
|---|
||

- Secure the main enclosure on each corner using the hole shown in the image.
  - 4 locations in total.
  - Use Screw 5.
  - Use Washer 1.
  - Use Loctite Threadlocker Purple.

|Main Enclosure Installation Hole|
|---|
||

### Step 21. Install the Push Button, Antennas & LIDAR
- Parts needed:
  - 3211 (Obstacle Avoidance Lidar S2L)
  - 3221, 3222 (Front & Rear Telemetry Antennas)
  - 3231 (Power Switch)
  - Screw 5 x4 (Socket Head Screw M3x8)
  - Washer 1 x4 (M3 General Purpose Washer 3.2 mm ID, 6 mm OD)
  - Würth Super RTV Silicone Black
  - Loctite Threadlocker Purple 222

- Remove the marked nuts from the antenna cables.
- Insert the antenna cables through the holes shown in the picture.
- Secure the antenna cables from outside with the nuts that were removed.
- Install the antennas on the outside.
  - Use a very small amount of Loctite Threadlocker Purple. Apply only to the threads near the base.

|Antenna Cable Nut| Antenna Cable Locations| Antenna Placement|
|--|--|--|
||||

- Remove the marked nut from the push button.
- Insert the push button in its location on the main enclosure.
- Secure it with the nut from inside.
  - Use Loctite Threadlocker Purple.

|Push Button Nut| Push Button Location|
|--|--|
|||

- Place the Lidar in its slot over the top cap.
  - Mind the orientation of the cable. It should go through the hole on the top cap.
- Secure with Screw 5 and Washer 1.
- Use Loctite Threadlocker Purple.
- Seal the gap around the cable with Würth Super RTV Silicone Black.

|Lidar Installation|
|---|
||

#### Harness Routing Notes

Route the pushbutton, LIDAR, and antenna harnesses while installing the enclosure-mounted components.

| Harness | Source | Destination | Routing notes |
| :--- | :--- | :--- | :--- |
| HAR-0001 Pushbutton | Bat_PCB J1 | Pushbutton | Route over the Battery PCB. Fix using the marked zip-tie provision. |
| HAR-0016 360 LIDAR | Main PCB U5 | S2L LIDAR | Route downward toward the connector and fix with the marked zip tie. |
| HAR-0028 Antenna | Antenna | HM30 | Route through the enclosure provisions to the middle plate. No special constraint or fixing noted. |

| HAR-0001 Pushbutton | HAR-0016 360 LIDAR | HAR-0028 Antenna |
| :---: | :---: | :---: |
| HAR-0001 pushbutton routing | HAR-0016 360 LIDAR routing | HAR-0028 antenna routing |

---

### Step 22. Install the PPP Adapter & Beacon
- Parts needed:
  - 2341 (PPP Adapter & Beacon Mount)
  - 3261 (Remote ID Beacon)
  - 3314 (PPP Adapter, CubeNode ETH)
  - Screw 5 x2 (Socket Head Screw M3x8)
  - Screw 10 x4 (Socket Head Screw M2x6)
  - Washer 1 x2 (M3 General Purpose Washer 3.2 mm ID, 6 mm OD)
  - Insert 3 x4 (M2 Threaded Inserts)
  - Loctite Threadlocker Purple 222
  - Double-Sided Tape

- Place Insert 3 to the holes shown in the picture on the PPP Adapter & Beacon Mount.
  - Use a soldering iron to place them inside the plastic.
  - 4 in total.

|Insert 3 Locations|
|---|
||

- Place the PPP Adapter & Beacon Mount inside the main enclosure, as shown in the picture.
  - Secure it with Screw 5 and Washer 1.
  - Use Loctite Threadlocker Purple.

|PPP Adapter & Beacon Mount Location|
|---|
||

- Place the PPP Adapter & Beacon on the mount, as shown in the picture.
  - Secure the Beacon with Screw 10, use Loctite Threadlocker Purple.
  - Secure the PPP Adapter on the mount with double-sided tape.

|PPP Adapter & Beacon Mount Installation|
|---|
||

#### Harness Routing Notes

Route PPP2ETH and Remote ID harnesses while installing the PPP adapter and beacon mount.

| Harness | Source | Destination | Routing notes |
| :--- | :--- | :--- | :--- |
| HAR-0023 / HAR-0024 / HAR-0025 PPP2ETH | Main_PCB J35, J36, J41 | PPP2ETH | Direct connections. HAR-0024 routes under the PPP/beacon mounting board; watch the mount and fix with the marked zip tie. |
| HAR-0026 Remote ID | Main_PCB J20 | Remote ID beacon | Direct connection. No special constraint or fixing noted. |

| HAR-0023 PPP2ETH | HAR-0024 PPP2ETH |
| :---: | :---: |
| HAR-0023 PPP2ETH routing | HAR-0024 PPP2ETH routing |
| HAR-0025 PPP2ETH | HAR-0026 Remote ID |
| HAR-0025 PPP2ETH routing | HAR-0026 Remote ID routing |

-----

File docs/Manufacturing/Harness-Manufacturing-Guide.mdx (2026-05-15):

---
title: Harnessing Guide
sidebar_position: 3
---

# Harness Manufacturing Guide

## Purpose

This guide explains how to manufacture and assemble the wiring harnesses for all of the components present on the dev kit build. Modifications include custom cut spool cables, pre made cables, pre crimped cables, and reducing length of default connectors.

Use the following wiring table for all of the connections TO/FROM for all of the dev kit’s systems: [Dev Kit Wire Data](https://docs.google.com/spreadsheets/d/1U9Jd1zW-IGLvGdLw63Ius3nsfnPE6wN_-VjMNnLCjd8/edit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)
The spreadsheet gives the full view of all connectors, mating connectors, wire gauge, estimated length, and suggested/default wire colors.

## How To Use This Guide

This guide is the canonical reference for harness fabrication: nailboard diagrams, BOMs, wire prep, termination, and pinout maps. Vehicle-side installation and photo-based routing walkthroughs are covered in the [Dev-Kit Manufacturing Guide](./Manufacturing-Guide.md), where each harness is placed in the assembly step that needs it.

## Vehicle Routing Quick Reference

Use this table only as a harness-side checklist for endpoints and major routing constraints. For the canonical route order, photos, and installation details, see the harness routing notes in the [Dev-Kit Manufacturing Guide](./Manufacturing-Guide.md).

| Harness | Source | Destination | Quick routing note |
| :--- | :--- | :--- | :--- |
| HAR-0001 Pushbutton | Bat_PCB J1 | Pushbutton | Route over the Battery PCB; use the marked zip-tie provision. |
| HAR-0002 BC_PCB Signal | Bat_PCB J2 | Main_PCB J43 | Direct PCB interconnect. |
| HAR-0003 BC_PCB SSR | Bat_PCB J3 | Main_PCB J46 | Direct PCB interconnect. |
| HAR-0004 / HAR-0005 / HAR-0006 / HAR-0007 ESC Power | Main_PCB J27 | ESC power leads | Route through the circular upper-plate opening to the middle plate. |
| HAR-0008 / HAR-0009 / HAR-0010 / HAR-0011 ESC Signal | Bat_PCB J2 | Main_PCB J43 | No special routing constraint currently noted. |
| HAR-0012 / HAR-0013 Side Payloads | Main_PCB J29, J37 | ATT_INT right/left | Route under the Main PCB to the side circular openings; watch telemetry air-unit clearance. |
| HAR-0014 Bottom Payload | Main_PCB J31, J39 | ATT_INT bottom | Route through the right-side and mid-plate openings to the underside; watch cable crowding and zip-tie points. |
| HAR-0015 Altimeter | Main PCB J8 | NRA15 | Route from the right-side top-plate entry to the bottom plate; watch other cables and marked zip tie. |
| HAR-0016 360 LIDAR | Main PCB U5 | S2L LIDAR | Route downward toward the connector; use the marked zip tie. |
| HAR-0017 Front Radar | Main PCB J49 | Front radar | Route from the right-side top-plate entry to the bottom plate; watch other cables and marked zip tie. |
| HAR-0018 HM30 Power | Main_PCB J27 | HM30 power | Route through the right-side top-plate opening. |
| HAR-0019 / HAR-0020 HM30 Signal | Bat_PCB J15, J17 | HM30 | Route through the right-side top-plate opening; watch other cables and secure with zip ties. |
| HAR-0021 / HAR-0022 Navigation | Main_PCB J7, J9 | F9P/Here 4, Mateksys | Route immediately to the right. |
| HAR-0023 / HAR-0024 / HAR-0025 PPP2ETH | Main_PCB J35, J36, J41 | PPP2ETH | Direct connections; HAR-0024 routes under the PPP/beacon mount and uses the marked zip tie. |
| HAR-0026 Remote ID | Main_PCB J20 | Remote ID beacon | Direct connection. |
| HAR-0027 SIYI Camera | HM30 LAN and power | SIYI A8 | Route through the right-side middle-plate opening to the underside; watch other cables and use zip ties as needed. |
| HAR-0028 Antenna | Antenna | HM30 | Route through the enclosure provisions to the middle plate. |

## Tools Required
* Soldering iron with hot air rework station
* Solder
* Wire stripper
* Wire cutter
* Heat shrink
* Heat shrink solder connectors
* Flathead screwdriver (1.5mm)
* Pliers
* Multimeter

## Quality Assurance (QC) Checklist
- [ ] **Visual:** Check for exposed strands or damaged insulation.
- [ ] **Mechanical:** Pull-test all crimps lightly to ensure retention.
- [ ] **Continuity:** Probe Pin 1 to Pin 1 (Tone check).
- [ ] **Polarity:** Verify Red is Positive, Black is Ground.

## HAR-0001 Pushbutton
| **FROM** | **TO**  |
| ---| --- |
| BC_PCB J25|Pushbutton |

<Steps>

  <Step title="Nailboard">

HAR-001 Wire Harness

  </Step>

  <Step title="Bill of Materials (Kitting)">

*Gather these parts before starting the build.*

| Item Type | Part Number | Description / Spec | Qty Needed |
| :--- | :--- | :--- | :--- |
| **Connector A** | 1704857 | 4-Pos Phoenix | 1 |
| **Terminals A** | Wire | Bare wire, twisted end | 4 |
| **Connector B** | Spade | Spade terminal | 4 |
| **Terminals B** | Wire | Bare wire | 4 |
| **Wire** | 18 AWG | Silicon |940mm |
| **Sleeving** | Optional| Mesh | 180 mm|

  </Step>

  <Step title="Wire Prep (Cut &amp; Strip)">

*Prepare all wires before assembly.*

| Wire ID | Color | Gauge | Cut Length | Strip A  | Strip B  |
| :--- | :--- | :--- | :--- | :--- | :--- |
| **W1** | Red | 18 AWG | 235mm | 6mm  | 6mm |
| **W2** | Red | 18 AWG | 235mm | 6mm | 6mm |
| **W3** | Red | 18 AWG | 235mm | 6mm | 6mm |
| **W4** | Black | 18 AWG | 235mm | 6mm | 6mm |

  </Step>

  <Step title="Termination &amp; Pinout Map">

*Connect End A to End B following this chart.*

| Wire ID | Color | From: 1704857  | To: Spade | Function / Signal |
| :--- | :--- | :--- | :--- | :--- |
| **W1** | Red | **Pin 1** | 1 | HV- |
| **W2** | Red | **Pin 2** | 2 | HV- SW |
| **W3** | Red | **Pin 3** | LED+| 12V |
| **W4** | Black | **Pin 4** | LED- | GND |

  </Step>

  <Step title="Assembly Instructions">

1.  **Prep:** Cut wires to length and strip insulation per Section 3.
2.  **Label:** Install identification markers per Section 5. *Do not shrink yet.*
4.  **Populate A:** Insert contacts into Connector A housing. *Verify "Click" and perform pull-back test.*
5.  **Crimp Side B:** Terminate Side B using crimping tool.
6.  **Populate B:** Insert contacts into Connector B housing.

  </Step>

</Steps>

## HAR-0002 BC_PCB Signal
| **FROM** | **TO**  |
| ---| --- |
| BC_PCB J25|Main_PCB J43 |

<Steps>

  <Step title="Nailboard">

HAR-002 Nail Board

  </Step>

  <Step title="Bill of Materials (Kitting)">

*Gather these parts before starting the build.*

| Item Type | Part Number | Description / Spec | Qty Needed |
| :--- | :--- | :--- | :--- |
| **Connector A** | 1704857 | 4-Pos Phoenix | 1 |
| **Terminals A** | Wire | Bare wire, twisted end | 4 |
| **Connector B** | 1704858 | 5-Pos Phoenix | 1 |
| **Terminals B** | Wire | Bare wire, twisted end | 4 |
| **Wire** | 20 AWG | Silicon | 240mm |
| **Sleeving** | Optional| Mesh | N/A|

  </Step>

  <Step title="Wire Prep (Cut &amp; Strip)">

*Prepare all wires before assembly.*

| Wire ID | Color | Gauge | Cut Length | Strip A  | Strip B  |
| :--- | :--- | :--- | :--- | :--- | :--- |
| **W1** | White | 20 AWG | 56mm | 6mm  | 6mm |
| **W2** | Blue | 20 AWG | 56mm | 6mm | 6mm |
| **W3** | Gray | 20 AWG | 56mm | 6mm | 6mm |
| **W4** | Green | 20 AWG | 56mm | 6mm | 6mm |

  </Step>

  <Step title="Termination &amp; Pinout Map">

*Connect End A to End B following this chart.*

| Wire ID | Color | From: 1704857  | To: 1704858 | Function / Signal |
| :--- | :--- | :--- | :--- | :--- |
| **W1** | White | **Pin 1** | 4 | I2C_SDA |
| **W2** | Blue | **Pin 2** | 3 | I2C_SCL |
| **W3** | Gray | **Pin 3** | 2| CAN_H |
| **W4** | Green | **Pin 4** | 1 | CAN_L |

  </Step>

  <Step title="Assembly Instructions">

1.  **Prep:** Cut wires to length and strip insulation per Section
4.  **Populate A:** Insert contacts into Connector A housing. *Verify "Click" and perform pull-back test.*
6.  **Populate B:** Insert contacts into Connector B housing.*Verify "Click" and perform pull-back test.*

  </Step>

</Steps>

## HAR-0003 BC_PCB SSR
| **FROM** | **TO**  |
| ---| --- |
| BC_PCB J25|Main_PCB J46 |

<Steps>

  <Step title="Nailboard">

HAR-003 Nail Board

  </Step>

  <Step title="Bill of Materials (Kitting)">

*Gather these parts before starting the build.*

| Item Type | Part Number | Description / Spec | Qty Needed |
| :--- | :--- | :--- | :--- |
| **Connector A** | 1704859| 6-Pos Phoenix | 1 |
| **Terminals A** | Wire | Bare wire, twisted end | 6|
| **Connector B** | 1704859| 6-Pos Phoenix | 1 |
| **Terminals B** | Wire | Bare wire, twisted end | 6|
| **Wire** | 20 AWG | Silicon | 50mm |
| **Sleeving** | Optional| Mesh | xx mm|

  </Step>

  <Step title="Wire Prep (Cut &amp; Strip)">

*Prepare all wires before assembly.*

| Wire ID | Color | Gauge | Cut Length | Strip A  | Strip B  |
| :--- | :--- | :--- | :--- | :--- | :--- |
| **W1** | Yellow| 20 AWG | 56mm | 6mm  | 6mm |
| **W2** | White| 20 AWG | 56mm | 6mm | 6mm |
| **W3** | White| 20 AWG | 56mm | 6mm | 6mm |
| **W4** | Red| 20 AWG | 56mm | 6mm | 6mm |
| **W5** | Red| 20 AWG | 56mm | 6mm | 6mm |
| **W6** | Black | 20 AWG | 56mm | 6mm | 6mm |

  </Step>

  <Step title="Termination &amp; Pinout Map">

*Connect End A to End B following this chart.*

| Wire ID | Color | From: 1704859| To: 1704859| Function / Signal |
| :--- | :--- | :--- | :--- | :--- |
| **W1** | Yellow| **Pin 1** | 6 | BYP_S|
| **W2** | White | **Pin 2** | 5 | SSR_S2|
| **W3** | White | **Pin 3** | 4| SSR_S|
| **W4** | Red | **Pin 4** | 3 | 12V|
| **W5** | Red | **Pin 5** | 2 | 5V|
| **W6** | Black | **Pin 6** | 1 | GND|

  </Step>

  <Step title="Assembly Instructions">

1.  **Prep:** Cut wires to length and strip insulation per Section
4.  **Populate A:** Insert contacts into Connector A housing. *Verify "Click" and perform pull-back test.*
6.  **Populate B:** Insert contacts into Connector B housing.*Verify "Click" and perform pull-back test.*

  </Step>

</Steps>

## HAR-0004 -> HAR-007 ESC Power
| **FROM** | **TO**  |
| ---| --- |
| Main_PCB J25|ESC1 PWR |
| Main_PCB J28|ESC2 PWR |
| Main_PCB J34|ESC3 PWR |
| Main_PCB J42|ESC4 PWR |

<Steps>

  <Step title="Nailboard">

HAR-004 Nail Board

HAR-005 Nail Board

HAR-006 Nail Board

HAR-007 Nail Board

  </Step>

  <Step title="Bill of Materials (Kitting)">

*Gather these parts before starting the build.*

| Item Type | Part Number | Description / Spec | Qty Needed |
| :--- | :--- | :--- | :--- |
| **Connector A** | XT60-M| 2-Pos XT-60| 1 |
| **Terminals A** | Wire | Solder | 2|
| **Wire** | 6 AWG | Silicon | 490mm |
| **Sleeving** | Required| 9.5mm ID heatshrink at motor arm bend | 7cm |

  </Step>

  <Step title="Wire Prep (Cut &amp; Strip)">

*Prepare all wires before assembly.*

| Wire ID | Color | Gauge | Cut Length | Strip A  | Strip B  |
| :--- | :--- | :--- | :--- | :--- | :--- |
| **W1** | Red| 6 AWG | 490mm | 4mm  | N/A |
| **W2** | Black| 6 AWG | 490mm | 4mm | N/A|

  </Step>

  <Step title="Termination &amp; Pinout Map">

*Connect End A to End B following this chart.*

| Wire ID | Color | From: XT60-M| To: ESC1| Function / Signal |
| :--- | :--- | :--- | :--- | :--- |
| **W1** | Red| **Pin 1** | Red| HV+|
| **W2** | Black| **Pin 2** | Black| HV-|

  </Step>

  <Step title="Assembly Instructions (Not finished)">

1.  **Prep:** Cut wires to length and strip insulation per Section 3.
4.  **Populate A:** Solder cables into Connector A housing.
6.  **Heatshrink:** Apply a 7cm 9.5mm ID heatshrink at the motor arm bend location. This heatshrink will protect the ESC Power and signal cables*

  </Step>

</Steps>

## HAR-0008 -> HAR-0011
| **FROM** | **TO**  |
| ---| --- |
| Main_PCB J23|ESC1 Signal |
| Main_PCB J27|ESC2 Signal |
| Main_PCB J32|ESC3 Signal |
| Main_PCB J40|ESC4 Signal |

<Steps>

  <Step title="Nailboard">

HAR-008 Nail Board

HAR-009 Nail Board

HAR-010 Nail Board

HAR-011 Nail Board

  </Step>

  <Step title="Bill of Materials (Kitting)">

*Gather these parts before starting the build.*

| Item Type | Part Number | Description / Spec | Qty Needed |
| :--- | :--- | :--- | :--- |
| **Connector A** | 1704858 | 5-Pos Phoenix | 1 |
| **Terminals A** | Wire | Bare wire, twisted end | 5 |
| **Wire** | 20 AWG | Silicon | 240mm |
| **Sleeving** | Required| 9.5mm ID Heatshrink at motor arm bend | 7cm |

  </Step>

  <Step title="Wire Prep (Cut &amp; Strip)">

*Prepare all wires before assembly.*

| Wire ID | Color | Gauge | Cut Length | Strip A  | Strip B  |
| :--- | :--- | :--- | :--- | :--- | :--- |
| **W1** | Yellow | 20 AWG | 56mm | 6mm  | 6mm |
| **W2** | Green | 20 AWG | 56mm | 6mm | 6mm |
| **W3** | Gray | 20 AWG | 56mm | 6mm | 6mm |
| **W4** | Black | 20 AWG | 56mm | 6mm | 6mm |
| **W5** | White | 20 AWG | 56mm | 6mm | 6mm |

  </Step>

  <Step title="Termination &amp; Pinout Map">

*Connect End A to End B following this chart.*

| Wire ID | Color | From: 1704857  | To: 1704858 | Function / Signal |
| :--- | :--- | :--- | :--- | :--- |
| **W1** | Yellow | **Pin 1** | 4 | GND |
| **W2** | Green | **Pin 2** | 3 | CAN1_L |
| **W3** | Gray | **Pin 3** | 2| CAN1_H |
| **W4** | Black | **Pin 4** | 1 | GND |
| **W5** | White | **Pin 5** | 1 | PWM  |

  </Step>

  <Step title="Assembly Instructions">

1.  **Prep:** Cut wires to length and strip insulation per Section
4.  **Populate A:** Insert contacts into Connector A housing. *Verify "Click" and perform pull-back test.*
6.  **Heatshrink:** Apply a 7cm 9.5mm ID Heatshrink at the motor arm bend location. This heatshrink will protect the ESC Power and signal cables*

  </Step>

</Steps>

## HAR-0012 -> HAR-0013 Side Payloads
| **FROM** | **TO**  |
| ---| --- |
| Main_PCB J29, J37|ATT_INT (right) |
| Main_PCB J30, J38|ATT_INT (left) |

<Steps>

  <Step title="Nailboard">

HAR-012 Nail Board

HAR-013 Nail Board

  </Step>

  <Step title="Bill of Materials (Kitting)">

*Gather these parts before starting the build.*

| Item Type | Part Number | Description / Spec | Qty Needed |
| :--- | :--- | :--- | :--- |
|  **Connector A**  | 1704859| 6-Pos Phoenix | 1 |
|  **Terminals A**  | Wire | Pre-crimped | 8|
|  **Connector B**  | 1704857| 4-Pos Phoenix | 1 |
|  **Terminals B**  | Wire | Pre-crimped | 4|
|  **Connector C**  | 204523-1201| 12-Pos Molex | 1 |
|  **Terminals C**  | Wire | Pre-crimped | 12|
|  **Wire**  | 26 AWG | Pre-Crimped Lead | 235mm |
|  **Sleeving**  | Optional| Mesh | xx mm|

  </Step>

  <Step title="Wire Prep (Cut &amp; Strip)">

*All wires connecting the payload to the PCBs will use pre-crimped jumper wires.*
**Mouser #: 538-79758-1149**

> **Build note:** Save the Molex-terminated cut ends/remnants from HAR-0012 and HAR-0013. These remnants are reused as the Molex tails for HAR-0014.

| Wire ID | Color | Gauge | Cut Length | Strip A  | Strip B  |
| :--- | :--- | :--- | :--- | :--- | :--- |
|  **W1**  | Black| 26 | 235mm | N/A| N/A|
|  **W2**  | Black| 26  | 235mm | N/A| N/A|
|  **W3**  | Black| 26  | 235mm | N/A| N/A|
|  **W4**  | Black| 26  | 235mm | N/A| N/A|
|  **W5**  | Black| 26  | 235mm  | N/A| N/A|
|  **W6**  | Black| 26  | 235mm | N/A| N/A|
|  **W7**  | Black| 26  | 235mm  | N/A| N/A|
|  **W8**  | Black| 26  | 235mm  | N/A| N/A|
|  **W9**  | Black| 26  | 235mm | N/A| N/A|
|  **W10**  | Black| 26  | 235mm | N/A| N/A|
|  **W11**  | Black| 26  | 235mm | N/A| N/A|
|  **W12**  | Black| 26  | 235mm  | N/A| N/A|

  </Step>

  <Step title="Termination &amp; Pinout Map">

*Connect End A or B to End C following this chart.*

| Wire ID | Color | From: 1704859| To: 204523-1201| Function / Signal |
| :--- | :--- | :--- | :--- | :--- |
|  **W1**  | Black|  **Pin 1**  | 6 | GND|
|  **W2**  | Black|  **Pin 1**  | 8 | GND|
|  **W3**  | Black|  **Pin 2**  | 10 | 12V_PL|
|  **W4**  | Black|  **Pin 3**  | 9| CAN2_L|
|  **W5**  | Black|  **Pin 4**  | 11 | CAN2_H|
|  **W6**  | Black|  **Pin 5**  | 12 | FMU_CH7|
|  **W7**  | Black |  **Pin 6**  | 2 | X|
|  **W8**  | Black |  **Pin 6**  | 4 | X|

| Wire ID | Color | From: 1704857| To: 204523-1201| Function / Signal |
| :--- | :--- | :--- | :--- | :--- |
|  **W9**  | Black|  **Pin 1**  | 1 | ETH_RX+|
|  **W10**  | Black|  **Pin 2**  | 3 | ETH_RX-|
|  **W11**  | Black|  **Pin 3**  | 5| ETH_TX+|
|  **W12**  | Black|  **Pin 4**  | 7 | ETH_TX-|

  </Step>

  <Step title="Assembly Instructions">

1.  **Populate A & B:** Insert contacts into Connector A housing. *Verify "Click" and perform pull-back test.*
2.  **Populate C:** Insert contacts into Connector B housing. Verify correct crimp orientation into [housing.](https://www.molex.com/content/dam/molex/molex-dot-com/products/automated/en-us/applicationspecificationspdf/505/505432/5054320000-AS-000.pdf)

  </Step>

</Steps>

## HAR-0014 Bottom Payload
| **FROM** | **TO**  |
| ---| --- |
| Main_PCB J31, J39|ATT_INT (bottom) |

<DemoImage src="Assembly-Guides/assets/images/Harnessing/HAR-014-reference.jpg" alt="Complete HAR-014 harness reference" caption="Complete HAR-014 bottom payload harness reference" />

<Steps>

  <Step title="Nailboard">

HAR-014 Nail Board

  </Step>

  <Step title="Bill of Materials (Kitting)">

*Gather these parts before starting the build.*

| Item Type | Part Number | Description / Spec | Qty Needed |
| :--- | :--- | :--- | :--- |
|  **Connector A**  | 1704859| 6-Pos Phoenix | 1 |
|  **Terminals A**  | 10-Conductor Cable | Twisted ends | 1 |
|  **Connector B**  | 1704857| 4-Pos Phoenix | 1 |
|  **Terminals B**  | 10-Conductor Cable | Twisted ends | 1 |
|  **Connector C**  | 204523-1201| 12-Pos Molex | 1 |
|  **Cable**  | [Amazon listing](https://www.amazon.com/dp/B0CSD52DL2) | 10-conductor, 26 AWG jacketed cable | 550mm |
|  **Molex tails**  | 538-79758-1149 | Molex-terminated cut ends/remnants saved from HAR-0012/HAR-0013 | 12 |

  </Step>

  <Step title="Wire Prep (Cut &amp; Strip)">

Build HAR-0014 from the 10-conductor jacketed cable and short Molex-terminated lead remnants. The jacketed cable end lands directly in the Phoenix connectors on the Main PCB side. The opposite end is spliced to the pre-crimped Molex tails for the bottom attachment interface.

1. Cut the 10-conductor cable to **550mm**.
2. Strip only enough outer jacket at each end to reach the connectors without stressing the conductors.
3. On the Phoenix end, strip each conductor to the Phoenix terminal requirement. No bare copper should be visible after insertion.
4. On the Molex end, prepare short pre-crimped Molex tails from the remnants created when cutting the side attachment harness leads.
5. Strip **5mm** from each cable conductor and each Molex tail to be spliced.
6. Slide one self-solder heat shrink sleeve onto each splice before joining conductors. For the red and black conductors, place both matching Molex tails into the same sleeve on the Molex side of the splice.

#### Splice procedure

1. Fan out the exposed strands slightly.
2. Push the two stripped ends together inline so the strands interlace. **Do not make a side-by-side pigtail splice.**
3. Twist the joined section lightly so it stays straight and compact.
4. Center the solder ring over the bare copper and position the adhesive rings over insulated wire.
5. Heat the solder ring first until it fully flows, then heat the sleeve ends to seal.
6. Let the splice cool before handling or pull-testing.

#### Final Check

- **Cable Length:** Confirm the jacketed cable was cut to **550mm**.
- **Splices:** Confirm each solder ring fully melted and no bare copper is visible outside the sleeve.
- **Phoenix End:** Confirm all conductors are fully seated and clamped in the Phoenix connectors.
- **Molex End:** Confirm all pre-crimped tails are fully seated in Connector C and pass a light pull test.

---

  </Step>

  <Step title="Termination &amp; Pinout Map">

*Connect the 10-conductor cable to the Phoenix connectors and splice it to the Molex tails following this chart.*

| Cable Color | From: 1704859 | To: 204523-1201 | Function / Signal |
| :--- | :--- | :--- | :--- |
| Black | **Pin 1** | 6 and 8 | GND |
| Orange | **Pin 2** | 10 | 12V_PL |
| White | **Pin 3** | 9 | CAN2_L |
| Gray | **Pin 4** | 11 | CAN2_H |
| Blue | **Pin 5** | 12 | FMU_CH7 |
| Red | **Pin 6** | 2 and 4 | 12VSW |

| Cable Color | From: 1704857 | To: 204523-1201 | Function / Signal |
| :--- | :--- | :--- | :--- |
| Yellow | **Pin 1** | 1 | ETH_RX+ |
| Purple | **Pin 2** | 3 | ETH_RX- |
| Brown | **Pin 3** | 5 | ETH_TX+ |
| Green | **Pin 4** | 7 | ETH_TX- |

> For the duplicated Molex positions, splice the single jacketed-cable conductor to both matching pre-crimped Molex tails in the same solder sleeve: Black to Molex pins 6 and 8, and Red to Molex pins 2 and 4.

  </Step>

  <Step title="Assembly Instructions">

1.  **Prep cable:** Cut the 10-conductor cable to 550mm, strip jacket/conductors, and prepare the Molex tails.
2.  **Splice Molex end:** Use self-solder heat shrink sleeves to connect the cable conductors to the Molex tails per the pinout map.
3.  **Populate Connector C:** Insert the Molex terminals into Connector C. Verify correct crimp orientation into the [housing.](https://www.molex.com/content/dam/molex/molex-dot-com/products/automated/en-us/applicationspecificationspdf/505/505432/5054320000-AS-000.pdf)
4.  **Populate Phoenix connectors:** Insert the bare conductor ends into Connector A and B. Verify the clamp captures the conductor and perform a light pull-back test.
5.  **Label:** Add identification markers as needed so the Phoenix conductors are easy to verify during vehicle integration.

  </Step>

</Steps>

## HAR-0015 Altimeter
| **FROM** | **TO** |
| --- | --- |
| Main_PCB J8  | NRA15 |

<Steps>

  <Step title="Nailboard">

HAR-015 Nail Board

  </Step>

  <Step title="Bill of Materials (Kitting)">

*Gather these parts before starting the build.*

| Item Type | Part Number | Description / Spec | Qty Needed |
|:--- |:--- |:--- |:--- |
| **Connector A** | 1704857 | 4-Pos Phoenix | 1 |
| **Terminals A** | Wire | Bare wire, twisted end | 4 |
| **Wire** | Default | Silicon | 190mm |
| **Sleeving** | Optional | Mesh | xx mm |

  </Step>

  <Step title="Wire Prep (Cut &amp; Strip)">

*Prepare all wires before assembly.*

| Wire ID | Color | Gauge | Cut Length | Strip A  | Strip B  |
| :--- | :--- | :--- | :--- | :--- | :--- |
| **W1** | Default| Default | 190mm | 6mm  | N/A|
| **W2** | Default| Default | 190mm | 6mm | N/A|
| **W3** | Default| Default | 190mm | 6mm | N/A|
| **W4** | Default| Default | 190mm | 6mm | N/A|

  </Step>

  <Step title="Termination &amp; Pinout Map">

*Connect End A to End B following this chart.*

| Wire ID | Color | From: 1704857  | To: NRA 15| Function / Signal |
| :--- | :--- | :--- | :--- | :--- |
| **W1** | White | **Pin 1** | 4 | GND|
| **W2** | Blue | **Pin 2** | 3 | CAN2_L|
| **W3** | Gray | **Pin 3** | 2| CAN2_H|
| **W4** | Green | **Pin 4** | 1 | 12V|

  </Step>

  <Step title="Assembly Instructions">

1.  **Prep:** Cut wires to length and strip insulation per Section 3.
3.  **Crimp Side A:** Terminate Side A using [Tool Name/Die].
4.  **Populate A:** Insert contacts into Connector A housing. *Verify "Click" and perform pull-back test.*

  </Step>

</Steps>

## HAR-0016 360 LIDAR
| **FROM** | **TO** |
| --- | --- |
| Main_PCB U5  | S2l |

<Steps>

  <Step title="Nailboard">

HAR-016 Nail Board

  </Step>

  <Step title="Bill of Materials (Kitting)">

Default cable that comes with 360° Lidar. No modification required

  </Step>

  <Step title="Wire Prep (Cut &amp; Strip)">

*Use the default cable supplied with the 360° LiDAR module.*

| Cable | Required Length (mm) |
| :--- | :--- |
| Default LiDAR cable | 195 |

  </Step>

  <Step title="Termination &amp; Pinout Map">

*Connect End A to End B following this chart.*

| Wire ID | Color | From: J5| To: NRA 15| Function / Signal |
| :--- | :--- | :--- | :--- | :--- |
| **W1** | Default| **Pin 1** | 1| 5V|
| **W2** | Default| **Pin 2** | 2| RX|
| **W3** | Default| **Pin 3** | 3| TX|
| **W4** | Default| **Pin 4** | 4| GND|
| **W4** | Default| **Pin 5** | 5| X|

  </Step>

  <Step title="Assembly Instructions">

N/A

  </Step>

</Steps>

## HAR-0017 Front Radar
| **FROM** | **TO** |
| --- | --- |
| Main_PCB J49 | Front Radar |

<Steps>

  <Step title="Nailboard">

HAR-017 Nail Board

  </Step>

  <Step title="Bill of Materials (Kitting)">

*Gather these parts before starting the build.*

| Item Type | Part Number | Description / Spec | Qty Needed |
| :--- | :--- | :--- | :--- |
| **Connector A** | 1704857 | 4-Pos Phoenix | 1 |
| **Terminals A** | Wire | Bare wire, twisted end | 4 |
| **Wire** | Default | Silicon | 190mm |
| **Sleeving** | Optional| Mesh | xx mm|

  </Step>

  <Step title="Wire Prep (Cut &amp; Strip)">

*Prepare all wires before assembly.*

| Wire ID | Color | Gauge | Cut Length | Strip A  | Strip B  |
| :--- | :--- | :--- | :--- | :--- | :--- |
| **W1** | Default| Default | 485 mm | 6mm  | N/A|
| **W2** | Default| Default | 485 mm | 6mm | N/A|
| **W3** | Default| Default | 485 mm | 6mm | N/A|
| **W4** | Default| Default | 485 mm | 6mm | N/A|

  </Step>

  <Step title="Termination &amp; Pinout Map">

*Connect End A to End B following this chart.*

| Wire ID | Color | From: 1704857  | To: NRA 15| Function / Signal |
| :--- | :--- | :--- | :--- | :--- |
| **W1** | Default| **Pin 1** | 4 | GND|
| **W2** | Default| **Pin 2** | 3 | CAN1_L|
| **W3** | Default| **Pin 3** | 2| CAN1_H|
| **W4** | Default| **Pin 4** | 1 | 12V|

  </Step>

  <Step title="Assembly Instructions">

1.  **Prep:** Cut wires to length and strip insulation per Section 3.
4.  **Populate A:** Insert contacts into Connector A housing. *Verify "Click" and perform pull-back test.*

  </Step>

</Steps>

## HAR-0018 HM30 Power
| **FROM** | **TO**  |
| ---| --- |
| Main_PCB J14|HM30 PWR |

<Steps>

  <Step title="Nailboard">

HAR-018 Nail Board

  </Step>

  <Step title="Bill of Materials (Kitting)">

*Gather these parts before starting the build.*

| Item Type | Part Number | Description / Spec | Qty Needed |
| :--- | :--- | :--- | :--- |
| **Connector A** | XT30-M| 2-Pos XT-30| 1 |
| **Terminals A** | Wire | Solder | 2|
| **Wire** | 16 AWG | Silicon | 170mm |
| **Sleeving** | Optional| Mesh|  xx mm|

  </Step>

  <Step title="Wire Prep (Cut &amp; Strip)">

*Prepare all wires before assembly.*

| Wire ID | Color | Gauge | Cut Length | Strip A  | Strip B  |
|:--- |:----- |:--- |:--- |:--- |
| **W1**  | Red | **Pin 1** | 185 | 10 |
| **W2**  | Black | **Pin 2** | 185 | 10 |

  </Step>

  <Step title="Termination &amp; Pinout Map">

*Connect End A to End B following this chart.*

| Wire ID | Color | From: 1704857  | To: Spade | Function / Signal |
| :--- | :--- | :--- | :--- | :--- |
| **W1** | Red | **Pin 1** | 1 | 12V |
| **W2** | Red | **Pin 2** | 2 | GND |

  </Step>

  <Step title="Assembly Instructions">

1.  **Prep:** Cut wires to length and strip insulation per Section 3.
3.  **Solder Side A:** Solder cables into housing.

  </Step>

</Steps>

## HAR-0019 -> HAR-0020 HM30 Signal
| **FROM** | **TO**  |
| ---| --- |
| Main_PCB J15|HM30 UART |
| Main_PCB J17|HM30 SBUS |

<Steps>

  <Step title="Nailboard">

HAR-019 Nail Board

HAR-020 Nail Board

  </Step>

  <Step title="Bill of Materials (Kitting)">

*Gather these parts before starting the build.*

| Item Type | Part Number | Description / Spec | Qty Needed |
| :--- | :--- | :--- | :--- |
|**4 Pin JST Cable** | N/A| JST, GH Connector Housing, 1.25mm Pitch, 4 Way| 1 |
|**3 Pin JST Cable** | N/A| JST, GH Connector Housing, 1.25mm Pitch, 3 Way| 1 |
| **Sleeving** | Optional| Mesh|  xx mm|

  </Step>

  <Step title="Wire Prep (Cut &amp; Strip)">

*Prepare all wires before assembly.*

Pre-made JST-GH cables. No crimping required — source cables at the required lengths below.

| Harness | Connector | Required Length (mm) |
| :--- | :--- | :--- |
| HAR-0019 (HM30 UART) | JST-GH 4P | 170 |
| HAR-0020 (HM30 SBUS) | JST-GH 3P | 160 |

  </Step>

  <Step title="Termination &amp; Pinout Map">

*Connect End A to End B following this chart.*

| Wire ID | Color | From: J15| To: HM30 UART| Function / Signal |
| :--- | :--- | :--- | :--- | :--- |
| **W1** | Default| **Pin 1** | 1| TX|
| **W2** | Default| **Pin 2** | 2| RX|
| **W1** | Default| **Pin 1** | 3| GND|
| **W2** | Default| **Pin 2** | 4| X|

| Wire ID | Color | From: J17| To: HM30 SBUS| Function / Signal |
| :--- | :--- | :--- | :--- | :--- |
| **W1** | Default| **Pin 1** | 1| IO_PPM_INPUT_AND_SBUS_INPUT|
| **W2** | Default| **Pin 2** | 2| GND|
| **W1** | Default| **Pin 1** | 3| x|

  </Step>

  <Step title="Assembly Instructions">

N/A

  </Step>

</Steps>

## HAR-0021 -> HAR-0022 Navigation
| **FROM** | **TO**  |
| ---| --- |
| Main_PCB J7|F9P |
| Main_PCB J9|Mateksys |

<Steps>

  <Step title="Nailboard">

HAR-021 Nail Board

HAR-022 Nail Board

  </Step>

  <Step title="Bill of Materials (Kitting)">

*Gather these parts before starting the build.*

| Item Type | Part Number | Description / Spec | Qty Needed |
| :--- | :--- | :--- | :--- |
|**4 Pin JST Cable** | N/A| JST, GH Connector Housing, 1.25mm Pitch, 4 Way| 2 |
| **Sleeving** | Optional| Mesh|  xx mm|

  </Step>

  <Step title="Wire Prep (Cut &amp; Strip)">

*Prepare all wires before assembly.*

Pre-made JST-GH cables. No crimping required — source cables at the required lengths below.

| Harness | Connector | Required Length  |
| :--- | :--- | :--- |
| HAR-0021 (F9P / Here4) | JST-GH 4P | 205mm |
| HAR-0022 (Mateksys) | JST-GH 4P | 70mm  |

  </Step>

  <Step title="Termination &amp; Pinout Map">

*Connect End A to End B following this chart.*

| Wire ID | Color | From: J9| To: M9N| Function / Signal |
| :--- | :--- | :--- | :--- | :--- |
| **W1** | Default| **Pin 1** | 1| GND|
| **W2** | Default| **Pin 2** | 2| CAN1_L|
| **W3** | Default| **Pin 1** | 3| CAN1_H|
| **W4** | Default| **Pin 2** | 4| 5V|

| Wire ID | Color | From: J7| To: F9P| Function / Signal |
| :--- | :--- | :--- | :--- | :--- |
| **W1** | Default| **Pin 1** | 1| GND|
| **W2** | Default| **Pin 2** | 2| CAN1_L|
| **W3** | Default| **Pin 1** | 3| CAN1_H|
| **W4** | Default| **Pin 2** | 4| 5V|

  </Step>

  <Step title="Assembly Instructions">

N/A

  </Step>

</Steps>

## HAR-0023 -> HAR-0025 PPP2ETH
| **FROM** | **TO**  |
| --- | --- |
| Main_PCB J35 | PPP2ETH |
| Main_PCB J36 | PPP2ETH |
| Main_PCB J41 | PPP2ETH |

<Steps>

  <Step title="Nailboard">

HAR-023 Nail Board

HAR-024 Nail Board

HAR-025 Nail Board

  </Step>

  <Step title="Bill of Materials (Kitting)">

*Gather these parts before starting the build.*

| Item Type | Part Number | Description / Spec | Qty Needed |
| :--- | :--- | :--- | :--- |
|**4 Pin JST Cable** | N/A| JST, GH Connector Housing, 1.25mm Pitch, 4 Way| 1 |
|**5 Pin JST Cable** | N/A| JST, GH Connector Housing, 1.25mm Pitch, 5 Way| 1 |
|**6 Pin JST Cable** | N/A| JST, GH Connector Housing, 1.25mm Pitch, 6 Way| 1 |
| **Sleeving** | Optional| Mesh|  xx mm|

  </Step>

  <Step title="Wire Prep (Cut &amp; Strip)">

*Prepare all wires before assembly.*

Pre-made JST-GH cables. No crimping required — source cables at the required lengths below.

| Harness | Connector | Required Length  |
| :--- | :--- | :--- |
| HAR-0023 (PPP2ETH CAN) | JST-GH 4P | 120mm |
| HAR-0024 (PPP2ETH Ethernet) | JST-GH 5P | 205mm |
| HAR-0025 (PPP2ETH UART) | JST-GH 6P | 155mm |

  </Step>

  <Step title="Termination &amp; Pinout Map">

*Connect End A to End B following this chart.*

| Wire ID | Color | From: J35| To: PPP2ETH| Function / Signal |
| :--- | :--- | :--- | :--- | :--- |
| **W1** | Default| **Pin 1** | 1| 5V|
| **W2** | Default| **Pin 2** | 2| CAN2_L|
| **W3** | Default| **Pin 3** | 3| CAN2_H|
| **W4** | Default| **Pin 4** | 4| GND|

| Wire ID | Color | From: J7| To: PPP2ETH| Function / Signal |
| :--- | :--- | :--- | :--- | :--- |
| **W1** | Default| **Pin 1** | 1| ETH_RX+|
| **W2** | Default| **Pin 2** | 2| ETH_RX-|
| **W3** | Default| **Pin 3** | 3| GND|
| **W4** | Default| **Pin 4** | 4| ETH_TX+|
| **W5** | Default| **Pin 5** | 5| ETH_TX-|

| Wire ID | Color | From: J7| To: PPP2ETH| Function / Signal |
| :--- | :--- | :--- | :--- | :--- |
| **W1** | Default| **Pin 1** | 1| 5V|
| **W2** | Default| **Pin 2** | 2| UART5_RX_TEL2|
| **W3** | Default| **Pin 3** | 3| UART5_TX_TEL2|
| **W4** | Default| **Pin 4** | 4| UART5_CTS_TEL2|
| **W5** | Default| **Pin 5** | 5| UART5_RTS_TEL2|
| **W6** | Default| **Pin 6** | 6| GND|

  </Step>

  <Step title="Assembly Instructions">

N/A

  </Step>

</Steps>

## HAR-0026 Remote ID

| **FROM** | **TO**  |
| ---| --- |
| Main_PCB J20|Remote ID CAN |

<Steps>

  <Step title="Nailboard">

HAR-026 Nail Board

  </Step>

  <Step title="Bill of Materials (Kitting)">

*Gather these parts before starting the build.*

| Item Type | Part Number | Description / Spec | Qty Needed |
| :--- | :--- | :--- | :--- |
|**4 Pin JST Cable** | N/A| JST, GH Connector Housing, 1.25mm Pitch, 4 Way| 1 |
| **Sleeving** | Optional| Mesh|  xx mm|

  </Step>

  <Step title="Wire Prep (Cut &amp; Strip)">

*Prepare all wires before assembly.*

Pre-made JST-GH cable. No crimping required — source cable at the required length below.

| Harness | Connector | Required Length  |
| :--- | :--- | :--- |
| HAR-0026 (Remote ID) | JST-GH 4P | 65mm |

  </Step>

  <Step title="Termination &amp; Pinout Map">

*Connect End A to End B following this chart.*

| Wire ID | Color | From: J20| To: RID| Function / Signal |
| :--- | :--- | :--- | :--- | :--- |
| **W1** | Default| **Pin 1** | 1| 5V|
| **W2** | Default| **Pin 2** | 2| CAN1_L|
| **W3** | Default| **Pin 3** | 3| CAN1_H|
| **W4** | Default| **Pin 4** | 4| GND|

  </Step>

  <Step title="Assembly Instructions">

N/A

  </Step>

</Steps>

## HAR-0027 SIYI Camera
| **FROM** | **TO**  |
| ---| --- |
| HM30 LAN & PWR|A8 PWR |
| HM30 LAN & PWR|A8 Video & Protocol |

<Steps>

  <Step title="Nailboard">

HAR-027 Nail Board

  </Step>

  <Step title="Bill of Materials (Kitting)">

*Gather these parts before starting the build.*

| Item Type | Part Number | Description / Spec | Qty Needed |
| :--- | :--- | :--- | :--- |
|**4 Pin JST Cable** | N/A| JST, GH Connector Housing, 1.25mm Pitch, 4 Way| 1 |
|**8 Pin JST Cable** | N/A| JST, GH Connector Housing, 1.25mm Pitch, 6 Way| 1 |
| **Sleeving** | Optional| Mesh|  xx mm|

  </Step>

  <Step title="Wire Prep (Cut &amp; Strip)">

*Prepare all wires before assembly.*

Pre-made JST-GH cables. No crimping required — source cables at the required lengths below.

| Harness | Connector | Required Length  |
| :--- | :--- | :--- |
| HAR-0027 power (4P) | JST-GH 4P | 325mm |
| HAR-0027 video (8P) | JST-GH 8P | 325mm |

  </Step>

  <Step title="Termination &amp; Pinout Map">

*Connect End A to End B following this chart.*

| Wire ID | Color | From: HM30 LAN & PWR| To: A8 PWR| Function / Signal |
| :--- | :--- | :--- | :--- | :--- |
| **W1** | Default| **Pin 1** | 1| 12V|
| **W2** | Default| **Pin 1** | 2| 12V|
| **W3** | Default| **Pin 2** | 3| GND|
| **W4** | Default| **Pin 2** | 4| GND|

 <br/>

| Wire ID | Color | From: HM30 LAN & PWR| To: A8 Vid| Function / Signal |
| :--- | :--- | :--- | :--- | :--- |
| **W1** | Default| **Pin 3** | 3| ETH_TX+|
| **W2** | Default| **Pin 4** | 4| ETH_TX-|
| **W3** | Default| **Pin 5** | 5| ETH_RX+|
| **W4** | Default| **Pin 6** | 6| ETH_RX-|

  </Step>

  <Step title="Assembly Instructions">

N/A

  </Step>

</Steps>

## HAR-0028 Antenna
| **FROM** | **TO**  |
| ---| --- |
| Antenna 1|HM30 |
| Antenna 2|HM30 |

<Steps>

  <Step title="Nailboard">

HAR-028 Nail Board

  </Step>

  <Step title="Bill of Materials (Kitting)">

*Gather these parts before starting the build.*

Pre made cables with SMA connector. Length adjustment not required.

  </Step>

  <Step title="Wire Prep (Cut &amp; Strip)">

N/A

  </Step>

  <Step title="Termination &amp; Pinout Map">

N/A

  </Step>

  <Step title="Assembly Instructions">

N/A

  </Step>

</Steps>

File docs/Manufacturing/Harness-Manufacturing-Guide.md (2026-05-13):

---
title: Harnessing Guide
sidebar_position: 3
---

# Harness Manufacturing Guide

## Purpose

This guide explains how to manufacture and assemble the wiring harnesses for all of the components present on the dev kit build. Modifications include custom cut spool cables, pre made cables, pre crimped cables, and reducing length of default connectors.

Use the following wiring table for all of the connections TO/FROM for all of the dev kit’s systems: [Dev Kit Wire Data](https://docs.google.com/spreadsheets/d/1U9Jd1zW-IGLvGdLw63Ius3nsfnPE6wN_-VjMNnLCjd8/edit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)
The spreadsheet gives the full view of all connectors, mating connectors, wire gauge, estimated length, and suggested/default wire colors.

## How To Use This Guide

This guide will detail the manufacturing process for all harnesses in no particular order. It is intended to be broken up and placed in the manufacturing guide according to the Quiver assembly steps. This is to allow harness routing that may be blocked by the installation of certain structural components. The user is encouraged to treat this document as a knowledge base and prep guide for the harnessing. Installation steps will be covered in the broader assembly guide.

## Tools Required
* Soldering iron with hot air rework station
* Solder
* Wire stripper
* Wire cutter
* Heat shrink
* Heat shrink solder connectors
* Flathead screwdriver (1.5mm)
* Pliers
* Multimeter

## Quality Assurance (QC) Checklist
- [ ] **Visual:** Check for exposed strands or damaged insulation.
- [ ] **Mechanical:** Pull-test all crimps lightly to ensure retention.
- [ ] **Continuity:** Probe Pin 1 to Pin 1 (Tone check).
- [ ] **Polarity:** Verify Red is Positive, Black is Ground.

## HAR-0001 Pushbutton
| **FROM** | **TO**  |
| ---| --- |
| BC_PCB J25|Pushbutton |

#### 1. Nailboard

HAR-001 Wire Harness

#### 2. Bill of Materials (Kitting)
*Gather these parts before starting the build.*

| Item Type | Part Number | Description / Spec | Qty Needed |
| :--- | :--- | :--- | :--- |
| **Connector A** | 1704857 | 4-Pos Phoenix | 1 |
| **Terminals A** | Wire | Bare wire, twisted end | 4 |
| **Connector B** | Spade | Spade terminal | 4 |
| **Terminals B** | Wire | Bare wire | 4 |
| **Wire** | 18 AWG | Silicon |940mm |
| **Sleeving** | Optional| Mesh | 180 mm|

#### 3. Wire Prep (Cut & Strip)
*Prepare all wires before assembly.*

| Wire ID | Color | Gauge | Cut Length | Strip A  | Strip B  |
| :--- | :--- | :--- | :--- | :--- | :--- |
| **W1** | Red | 18 AWG | 235mm | 6mm  | 6mm |
| **W2** | Red | 18 AWG | 235mm | 6mm | 6mm |
| **W3** | Red | 18 AWG | 235mm | 6mm | 6mm |
| **W4** | Black | 18 AWG | 235mm | 6mm | 6mm |

#### 4. Termination & Pinout Map
*Connect End A to End B following this chart.*

| Wire ID | Color | From: 1704857  | To: Spade | Function / Signal |
| :--- | :--- | :--- | :--- | :--- |
| **W1** | Red | **Pin 1** | 1 | HV- |
| **W2** | Red | **Pin 2** | 2 | HV- SW |
| **W3** | Red | **Pin 3** | LED+| 12V |
| **W4** | Black | **Pin 4** | LED- | GND |

#### 5. Assembly Instructions
1.  **Prep:** Cut wires to length and strip insulation per Section 3.
2.  **Label:** Install identification markers per Section 5. *Do not shrink yet.*
4.  **Populate A:** Insert contacts into Connector A housing. *Verify "Click" and perform pull-back test.*
5.  **Crimp Side B:** Terminate Side B using crimping tool.
6.  **Populate B:** Insert contacts into Connector B housing.

---

#### 6. Installation & Routing (Vehicle Integration)
*Instructions for the technician installing this harness into the chassis.*

* **Source Connection:** Bat_PCB, J1
* **Destination Connection:** Pushbutton
* **Routing Path:**
    * Path - Over Battery PCB
    * Constraint - N/A
    * Fixing - Zip Tie Provision Circled in red



## HAR-0002 BC_PCB Signal
| **FROM** | **TO**  |
| ---| --- |
| BC_PCB J25|Main_PCB J43 |

#### 1. Nailboard

HAR-002 Nail Board

#### 2. Bill of Materials (Kitting)
*Gather these parts before starting the build.*

| Item Type | Part Number | Description / Spec | Qty Needed |
| :--- | :--- | :--- | :--- |
| **Connector A** | 1704857 | 4-Pos Phoenix | 1 |
| **Terminals A** | Wire | Bare wire, twisted end | 4 |
| **Connector B** | 1704858 | 5-Pos Phoenix | 1 |
| **Terminals B** | Wire | Bare wire, twisted end | 4 |
| **Wire** | 20 AWG | Silicon | 240mm |
| **Sleeving** | Optional| Mesh | N/A|

#### 3. Wire Prep (Cut & Strip)
*Prepare all wires before assembly.*

| Wire ID | Color | Gauge | Cut Length | Strip A  | Strip B  |
| :--- | :--- | :--- | :--- | :--- | :--- |
| **W1** | White | 20 AWG | 56mm | 6mm  | 6mm |
| **W2** | Blue | 20 AWG | 56mm | 6mm | 6mm |
| **W3** | Gray | 20 AWG | 56mm | 6mm | 6mm |
| **W4** | Green | 20 AWG | 56mm | 6mm | 6mm |

#### 4. Termination & Pinout Map
*Connect End A to End B following this chart.*

| Wire ID | Color | From: 1704857  | To: 1704858 | Function / Signal |
| :--- | :--- | :--- | :--- | :--- |
| **W1** | White | **Pin 1** | 4 | I2C_SDA |
| **W2** | Blue | **Pin 2** | 3 | I2C_SCL |
| **W3** | Gray | **Pin 3** | 2| CAN_H |
| **W4** | Green | **Pin 4** | 1 | CAN_L |

#### 5. Assembly Instructions
1.  **Prep:** Cut wires to length and strip insulation per Section
4.  **Populate A:** Insert contacts into Connector A housing. *Verify "Click" and perform pull-back test.*
6.  **Populate B:** Insert contacts into Connector B housing.*Verify "Click" and perform pull-back test.*

---

#### 6. Installation & Routing (Vehicle Integration)
Instructions for the technician installing this harness into the chassis.*

* **Source Connection:** Bat_PCB, J2
* **Destination Connection:** Main_PCB, J43
* **Routing Path:**
    * Path - N/A
    * Constraint - N/A
    * Fixing - N/A


## HAR-0003 BC_PCB SSR
| **FROM** | **TO**  |
| ---| --- |
| BC_PCB J25|Main_PCB J46 |

#### 1. Nailboard

HAR-003 Nail Board

#### 2. Bill of Materials (Kitting)
*Gather these parts before starting the build.*

| Item Type | Part Number | Description / Spec | Qty Needed |
| :--- | :--- | :--- | :--- |
| **Connector A** | 1704859| 6-Pos Phoenix | 1 |
| **Terminals A** | Wire | Bare wire, twisted end | 6|
| **Connector B** | 1704859| 6-Pos Phoenix | 1 |
| **Terminals B** | Wire | Bare wire, twisted end | 6|
| **Wire** | 20 AWG | Silicon | 50mm |
| **Sleeving** | Optional| Mesh | xx mm|

#### 3. Wire Prep (Cut & Strip)
*Prepare all wires before assembly.*

| Wire ID | Color | Gauge | Cut Length | Strip A  | Strip B  |
| :--- | :--- | :--- | :--- | :--- | :--- |
| **W1** | Yellow| 20 AWG | 56mm | 6mm  | 6mm |
| **W2** | White| 20 AWG | 56mm | 6mm | 6mm |
| **W3** | White| 20 AWG | 56mm | 6mm | 6mm |
| **W4** | Red| 20 AWG | 56mm | 6mm | 6mm |
| **W5** | Red| 20 AWG | 56mm | 6mm | 6mm |
| **W6** | Black | 20 AWG | 56mm | 6mm | 6mm |

#### 4. Termination & Pinout Map
*Connect End A to End B following this chart.*

| Wire ID | Color | From: 1704859| To: 1704859| Function / Signal |
| :--- | :--- | :--- | :--- | :--- |
| **W1** | Yellow| **Pin 1** | 6 | BYP_S|
| **W2** | White | **Pin 2** | 5 | SSR_S2|
| **W3** | White | **Pin 3** | 4| SSR_S|
| **W4** | Red | **Pin 4** | 3 | 12V|
| **W5** | Red | **Pin 5** | 2 | 5V|
| **W6** | Black | **Pin 6** | 1 | GND|

#### 5. Assembly Instructions
1.  **Prep:** Cut wires to length and strip insulation per Section
4.  **Populate A:** Insert contacts into Connector A housing. *Verify "Click" and perform pull-back test.*
6.  **Populate B:** Insert contacts into Connector B housing.*Verify "Click" and perform pull-back test.*

---

#### 6. Installation & Routing (Vehicle Integration)
*Instructions for the technician installing this harness into the chassis.*

* **Source Connection:** Bat_PCB, J3
* **Destination Connection:** Main_PCB, J46
* **Routing Path:**
    * Path -
    * Constraint -
    * Fixing -


## HAR-0004 -> HAR-007 ESC Power
| **FROM** | **TO**  |
| ---| --- |
| Main_PCB J25|ESC1 PWR |
| Main_PCB J28|ESC2 PWR |
| Main_PCB J34|ESC3 PWR |
| Main_PCB J42|ESC4 PWR |

#### 1. Nailboard

HAR-004 Nail Board

HAR-005 Nail Board

HAR-006 Nail Board

HAR-007 Nail Board

#### 2. Bill of Materials (Kitting)
*Gather these parts before starting the build.*

| Item Type | Part Number | Description / Spec | Qty Needed |
| :--- | :--- | :--- | :--- |
| **Connector A** | XT60-M| 2-Pos XT-60| 1 |
| **Terminals A** | Wire | Solder | 2|
| **Wire** | 6 AWG | Silicon | 490mm |
| **Sleeving** | Required| 9.5mm ID heatshrink at motor arm bend | 7cm |

#### 3. Wire Prep (Cut & Strip)
*Prepare all wires before assembly.*

| Wire ID | Color | Gauge | Cut Length | Strip A  | Strip B  |
| :--- | :--- | :--- | :--- | :--- | :--- |
| **W1** | Red| 6 AWG | 490mm | 4mm  | N/A |
| **W2** | Black| 6 AWG | 490mm | 4mm | N/A|

#### 4. Termination & Pinout Map
*Connect End A to End B following this chart.*

| Wire ID | Color | From: XT60-M| To: ESC1| Function / Signal |
| :--- | :--- | :--- | :--- | :--- |
| **W1** | Red| **Pin 1** | Red| HV+|
| **W2** | Black| **Pin 2** | Black| HV-|

#### 6. Assembly Instructions (Not finished)
1.  **Prep:** Cut wires to length and strip insulation per Section 3.
4.  **Populate A:** Solder cables into Connector A housing.
6.  **Heatshrink:** Apply a 7cm 9.5mm ID heatshrink at the motor arm bend location. This heatshrink will protect the ESC Power and signal cables*

---

#### 7. Installation & Routing (Vehicle Integration)
*Instructions for the technician installing this harness into the chassis.*

* **Source Connection:** Main_PCB, J27
* **Destination Connection:** ESC 1 PWR
* **Routing Path:**
    * Path - Through circular hole on upper plate to middle plate
    * Constraint - N/A
    * Fixing - N/A


## HAR-0008 -> HAR-0011
| **FROM** | **TO**  |
| ---| --- |
| Main_PCB J23|ESC1 Signal |
| Main_PCB J27|ESC2 Signal |
| Main_PCB J32|ESC3 Signal |
| Main_PCB J40|ESC4 Signal |

#### 1. Nailboard

HAR-008 Nail Board

HAR-009 Nail Board

HAR-010 Nail Board

HAR-011 Nail Board

#### 2. Bill of Materials (Kitting)
*Gather these parts before starting the build.*

| Item Type | Part Number | Description / Spec | Qty Needed |
| :--- | :--- | :--- | :--- |
| **Connector A** | 1704858 | 5-Pos Phoenix | 1 |
| **Terminals A** | Wire | Bare wire, twisted end | 5 |
| **Wire** | 20 AWG | Silicon | 240mm |
| **Sleeving** | Required| 9.5mm ID Heatshrink at motor arm bend | 7cm |

#### 3. Wire Prep (Cut & Strip)
*Prepare all wires before assembly.*

| Wire ID | Color | Gauge | Cut Length | Strip A  | Strip B  |
| :--- | :--- | :--- | :--- | :--- | :--- |
| **W1** | Yellow | 20 AWG | 56mm | 6mm  | 6mm |
| **W2** | Green | 20 AWG | 56mm | 6mm | 6mm |
| **W3** | Gray | 20 AWG | 56mm | 6mm | 6mm |
| **W4** | Black | 20 AWG | 56mm | 6mm | 6mm |
| **W5** | White | 20 AWG | 56mm | 6mm | 6mm |

#### 4. Termination & Pinout Map
*Connect End A to End B following this chart.*

| Wire ID | Color | From: 1704857  | To: 1704858 | Function / Signal |
| :--- | :--- | :--- | :--- | :--- |
| **W1** | Yellow | **Pin 1** | 4 | GND |
| **W2** | Green | **Pin 2** | 3 | CAN1_L |
| **W3** | Gray | **Pin 3** | 2| CAN1_H |
| **W4** | Black | **Pin 4** | 1 | GND |
| **W5** | White | **Pin 5** | 1 | PWM  |

#### 5. Assembly Instructions
1.  **Prep:** Cut wires to length and strip insulation per Section
4.  **Populate A:** Insert contacts into Connector A housing. *Verify "Click" and perform pull-back test.*
6.  **Heatshrink:** Apply a 7cm 9.5mm ID Heatshrink at the motor arm bend location. This heatshrink will protect the ESC Power and signal cables*

---

#### 6. Installation & Routing (Vehicle Integration)
Instructions for the technician installing this harness into the chassis.*

* **Source Connection:** Bat_PCB, J2
* **Destination Connection:** Main_PCB, J43
* **Routing Path:**
    * Path - N/A
    * Constraint - N/A
    * Fixing - N/A



## HAR-0012 -> HAR-0013 Side Payloads
| **FROM** | **TO**  |
| ---| --- |
| Main_PCB J29, J37|ATT_INT (right) |
| Main_PCB J30, J38|ATT_INT (left) |

#### 1. Nailboard

HAR-012 Nail Board

HAR-013 Nail Board

#### 2. Bill of Materials (Kitting)
*Gather these parts before starting the build.*

| Item Type | Part Number | Description / Spec | Qty Needed |
| :--- | :--- | :--- | :--- |
|  **Connector A**  | 1704859| 6-Pos Phoenix | 1 |
|  **Terminals A**  | Wire | Pre-crimped | 8|
|  **Connector B**  | 1704857| 4-Pos Phoenix | 1 |
|  **Terminals B**  | Wire | Pre-crimped | 4|
|  **Connector C**  | 204523-1201| 12-Pos Molex | 1 |
|  **Terminals C**  | Wire | Pre-crimped | 12|
|  **Wire**  | 26 AWG | Pre-Crimped Lead | 235mm |
|  **Sleeving**  | Optional| Mesh | xx mm|

#### 3. Wire Prep (Cut & Strip)
*All wires connecting the payload to the PCBs will use pre-crimped jumper wires.*
**Mouser #: 538-79758-1149**

> **Build note:** Save the Molex-terminated cut ends/remnants from HAR-0012 and HAR-0013. These remnants are reused as the Molex tails for HAR-0014.

| Wire ID | Color | Gauge | Cut Length | Strip A  | Strip B  |
| :--- | :--- | :--- | :--- | :--- | :--- |
|  **W1**  | Black| 26 | 235mm | N/A| N/A|
|  **W2**  | Black| 26  | 235mm | N/A| N/A|
|  **W3**  | Black| 26  | 235mm | N/A| N/A|
|  **W4**  | Black| 26  | 235mm | N/A| N/A|
|  **W5**  | Black| 26  | 235mm  | N/A| N/A|
|  **W6**  | Black| 26  | 235mm | N/A| N/A|
|  **W7**  | Black| 26  | 235mm  | N/A| N/A|
|  **W8**  | Black| 26  | 235mm  | N/A| N/A|
|  **W9**  | Black| 26  | 235mm | N/A| N/A|
|  **W10**  | Black| 26  | 235mm | N/A| N/A|
|  **W11**  | Black| 26  | 235mm | N/A| N/A|
|  **W12**  | Black| 26  | 235mm  | N/A| N/A|

#### 4. Termination & Pinout Map
*Connect End A or B to End C following this chart.*

| Wire ID | Color | From: 1704859| To: 204523-1201| Function / Signal |
| :--- | :--- | :--- | :--- | :--- |
|  **W1**  | Black|  **Pin 1**  | 6 | GND|
|  **W2**  | Black|  **Pin 1**  | 8 | GND|
|  **W3**  | Black|  **Pin 2**  | 10 | 12V_PL|
|  **W4**  | Black|  **Pin 3**  | 9| CAN2_L|
|  **W5**  | Black|  **Pin 4**  | 11 | CAN2_H|
|  **W6**  | Black|  **Pin 5**  | 12 | FMU_CH7|
|  **W7**  | Black |  **Pin 6**  | 2 | X|
|  **W8**  | Black |  **Pin 6**  | 4 | X|

| Wire ID | Color | From: 1704857| To: 204523-1201| Function / Signal |
| :--- | :--- | :--- | :--- | :--- |
|  **W9**  | Black|  **Pin 1**  | 1 | ETH_RX+|
|  **W10**  | Black|  **Pin 2**  | 3 | ETH_RX-|
|  **W11**  | Black|  **Pin 3**  | 5| ETH_TX+|
|  **W12**  | Black|  **Pin 4**  | 7 | ETH_TX-|

#### 5. Assembly Instructions
1.  **Populate A & B:** Insert contacts into Connector A housing. *Verify "Click" and perform pull-back test.*
2.  **Populate C:** Insert contacts into Connector B housing. Verify correct crimp orientation into [housing.](https://www.molex.com/content/dam/molex/molex-dot-com/products/automated/en-us/applicationspecificationspdf/505/505432/5054320000-AS-000.pdf)

---

#### 6. Installation & Routing (Vehicle Integration)
*Instructions for the technician installing this harness into the chassis. Mirror the installation path for the payload on the opposite side.*

* **Source Connection:** Main_PCB J29 & J37
* **Destination Connection:** ATT_INT (right)
* **Routing Path:**
 * Path -   Underneath MainPCB to middle plate side circular openings
 * Constraint -   Telemetry air unit location
 * Fixing -   N/A


## HAR-0014 Bottom Payload
| **FROM** | **TO**  |
| ---| --- |
| Main_PCB J31, J39|ATT_INT (bottom) |

#### 1. Nailboard

HAR-014 Nail Board

#### Complete Harness Reference Photo

This photo shows a complete HAR-0014 harness. Use the nailboard and pinout tables as the source of truth; this photo is included as a visual reference for the finished physical harness layout.

Complete HAR-014 harness reference

#### 2. Bill of Materials (Kitting)
*Gather these parts before starting the build.*

| Item Type | Part Number | Description / Spec | Qty Needed |
| :--- | :--- | :--- | :--- |
|  **Connector A**  | 1704859| 6-Pos Phoenix | 1 |
|  **Terminals A**  | 10-Conductor Cable | Twisted ends | 1 |
|  **Connector B**  | 1704857| 4-Pos Phoenix | 1 |
|  **Terminals B**  | 10-Conductor Cable | Twisted ends | 1 |
|  **Connector C**  | 204523-1201| 12-Pos Molex | 1 |
|  **Cable**  | [Amazon listing](https://www.amazon.com/dp/B0CSD52DL2) | 10-conductor, 26 AWG jacketed cable | 550mm |
|  **Molex tails**  | 538-79758-1149 | Molex-terminated cut ends/remnants saved from HAR-0012/HAR-0013 | 12 |

#### 3. Wire Prep (Cut & Strip)

Build HAR-0014 from the 10-conductor jacketed cable and short Molex-terminated lead remnants. The jacketed cable end lands directly in the Phoenix connectors on the Main PCB side. The opposite end is spliced to the pre-crimped Molex tails for the bottom attachment interface.

1. Cut the 10-conductor cable to **550mm**.
2. Strip only enough outer jacket at each end to reach the connectors without stressing the conductors.
3. On the Phoenix end, strip each conductor to the Phoenix terminal requirement. No bare copper should be visible after insertion.
4. On the Molex end, prepare short pre-crimped Molex tails from the remnants created when cutting the side attachment harness leads.
5. Strip **5mm** from each cable conductor and each Molex tail to be spliced.
6. Slide one self-solder heat shrink sleeve onto each splice before joining conductors. For the red and black conductors, place both matching Molex tails into the same sleeve on the Molex side of the splice.

#### Splice procedure

1. Fan out the exposed strands slightly.
2. Push the two stripped ends together inline so the strands interlace. **Do not make a side-by-side pigtail splice.**
3. Twist the joined section lightly so it stays straight and compact.
4. Center the solder ring over the bare copper and position the adhesive rings over insulated wire.
5. Heat the solder ring first until it fully flows, then heat the sleeve ends to seal.
6. Let the splice cool before handling or pull-testing.

#### Final Check

- **Cable Length:** Confirm the jacketed cable was cut to **550mm**.
- **Splices:** Confirm each solder ring fully melted and no bare copper is visible outside the sleeve.
- **Phoenix End:** Confirm all conductors are fully seated and clamped in the Phoenix connectors.
- **Molex End:** Confirm all pre-crimped tails are fully seated in Connector C and pass a light pull test.

---

#### 4. Termination & Pinout Map
*Connect the 10-conductor cable to the Phoenix connectors and splice it to the Molex tails following this chart.*

| Cable Color | From: 1704859 | To: 204523-1201 | Function / Signal |
| :--- | :--- | :--- | :--- |
| Black | **Pin 1** | 6 and 8 | GND |
| Orange | **Pin 2** | 10 | 12V_PL |
| White | **Pin 3** | 9 | CAN2_L |
| Gray | **Pin 4** | 11 | CAN2_H |
| Blue | **Pin 5** | 12 | FMU_CH7 |
| Red | **Pin 6** | 2 and 4 | 12VSW |

| Cable Color | From: 1704857 | To: 204523-1201 | Function / Signal |
| :--- | :--- | :--- | :--- |
| Yellow | **Pin 1** | 1 | ETH_RX+ |
| Purple | **Pin 2** | 3 | ETH_RX- |
| Brown | **Pin 3** | 5 | ETH_TX+ |
| Green | **Pin 4** | 7 | ETH_TX- |

> For the duplicated Molex positions, splice the single jacketed-cable conductor to both matching pre-crimped Molex tails in the same solder sleeve: Black to Molex pins 6 and 8, and Red to Molex pins 2 and 4.

#### 5. Assembly Instructions
1.  **Prep cable:** Cut the 10-conductor cable to 550mm, strip jacket/conductors, and prepare the Molex tails.
2.  **Splice Molex end:** Use self-solder heat shrink sleeves to connect the cable conductors to the Molex tails per the pinout map.
3.  **Populate Connector C:** Insert the Molex terminals into Connector C. Verify correct crimp orientation into the [housing.](https://www.molex.com/content/dam/molex/molex-dot-com/products/automated/en-us/applicationspecificationspdf/505/505432/5054320000-AS-000.pdf)
4.  **Populate Phoenix connectors:** Insert the bare conductor ends into Connector A and B. Verify the clamp captures the conductor and perform a light pull-back test.
5.  **Label:** Add identification markers as needed so the Phoenix conductors are easy to verify during vehicle integration.

#### 6. Installation & Routing (Vehicle Integration)
*Instructions for the technician installing this harness into the chassis.*

* **Source Connection:** Main_PCB J31 & J39
* **Destination Connection:** ATT INT (bottom)
* **Routing Path:**
 * Path -   Top Plate, right side opening, through mid plate openings, attached to the underside of the bottom plate
 * Constraint -   Number of cables passing through openings
 * Fixing -   Various zip ties show in red


## HAR-0015 Altimeter
| **FROM** | **TO** |
| --- | --- |
| Main_PCB J8  | NRA15 |

#### 1. Nailboard

HAR-015 Nail Board

#### 2. Bill of Materials (Kitting)
*Gather these parts before starting the build.*

| Item Type | Part Number | Description / Spec | Qty Needed |
|:--- |:--- |:--- |:--- |
| **Connector A** | 1704857 | 4-Pos Phoenix | 1 |
| **Terminals A** | Wire | Bare wire, twisted end | 4 |
| **Wire** | Default | Silicon | 190mm |
| **Sleeving** | Optional | Mesh | xx mm |

#### 3. Wire Prep (Cut & Strip)
*Prepare all wires before assembly.*

| Wire ID | Color | Gauge | Cut Length | Strip A  | Strip B  |
| :--- | :--- | :--- | :--- | :--- | :--- |
| **W1** | Default| Default | 190mm | 6mm  | N/A|
| **W2** | Default| Default | 190mm | 6mm | N/A|
| **W3** | Default| Default | 190mm | 6mm | N/A|
| **W4** | Default| Default | 190mm | 6mm | N/A|

#### 4. Termination & Pinout Map
*Connect End A to End B following this chart.*

| Wire ID | Color | From: 1704857  | To: NRA 15| Function / Signal |
| :--- | :--- | :--- | :--- | :--- |
| **W1** | White | **Pin 1** | 4 | GND|
| **W2** | Blue | **Pin 2** | 3 | CAN2_L|
| **W3** | Gray | **Pin 3** | 2| CAN2_H|
| **W4** | Green | **Pin 4** | 1 | 12V|

#### 5. Assembly Instructions
1.  **Prep:** Cut wires to length and strip insulation per Section 3.
3.  **Crimp Side A:** Terminate Side A using [Tool Name/Die].
4.  **Populate A:** Insert contacts into Connector A housing. *Verify "Click" and perform pull-back test.*

---

#### 6. Installation & Routing (Vehicle Integration)
*Instructions for the technician installing this harness into the chassis.*

* **Source Connection:** Main PCB, J8
* **Destination Connection:** NRA 15
* **Routing Path:**
    * Path - Right side top plate entry to bottom plate
    * Constraint - other cables
    * Fixing - Zip tie in red

 

## HAR-0016 360 LIDAR
| **FROM** | **TO** |
| --- | --- |
| Main_PCB U5  | S2l |

#### 1. Nailboard

HAR-016 Nail Board

#### 2. Bill of Materials (Kitting)
Default cable that comes with 360° Lidar. No modification required

#### 3. Wire Prep (Cut & Strip)
*Use the default cable supplied with the 360° LiDAR module.*

| Cable | Required Length (mm) |
| :--- | :--- |
| Default LiDAR cable | 195 |

#### 4. Termination & Pinout Map
*Connect End A to End B following this chart.*

| Wire ID | Color | From: J5| To: NRA 15| Function / Signal |
| :--- | :--- | :--- | :--- | :--- |
| **W1** | Default| **Pin 1** | 1| 5V|
| **W2** | Default| **Pin 2** | 2| RX|
| **W3** | Default| **Pin 3** | 3| TX|
| **W4** | Default| **Pin 4** | 4| GND|
| **W4** | Default| **Pin 5** | 5| X|

#### 5. Assembly Instructions
N/A

---

#### 6. Installation & Routing (Vehicle Integration)
*Instructions for the technician installing this harness into the chassis.*

* **Source Connection:** Main PCB, U5
* **Destination Connection:** S2L Lidar
* **Routing Path:**
    * Path - Downward towards connector
    * Constraint - N/A
    * Fixing - Zip tie in red



## HAR-0017 Front Radar
| **FROM** | **TO** |
| --- | --- |
| Main_PCB J49 | Front Radar |

#### 1. Nailboard

HAR-017 Nail Board

#### 2. Bill of Materials (Kitting)
*Gather these parts before starting the build.*

| Item Type | Part Number | Description / Spec | Qty Needed |
| :--- | :--- | :--- | :--- |
| **Connector A** | 1704857 | 4-Pos Phoenix | 1 |
| **Terminals A** | Wire | Bare wire, twisted end | 4 |
| **Wire** | Default | Silicon | 190mm |
| **Sleeving** | Optional| Mesh | xx mm|

#### 3. Wire Prep (Cut & Strip)
*Prepare all wires before assembly.*

| Wire ID | Color | Gauge | Cut Length | Strip A  | Strip B  |
| :--- | :--- | :--- | :--- | :--- | :--- |
| **W1** | Default| Default | 485 mm | 6mm  | N/A|
| **W2** | Default| Default | 485 mm | 6mm | N/A|
| **W3** | Default| Default | 485 mm | 6mm | N/A|
| **W4** | Default| Default | 485 mm | 6mm | N/A|

#### 4. Termination & Pinout Map
*Connect End A to End B following this chart.*

| Wire ID | Color | From: 1704857  | To: NRA 15| Function / Signal |
| :--- | :--- | :--- | :--- | :--- |
| **W1** | Default| **Pin 1** | 4 | GND|
| **W2** | Default| **Pin 2** | 3 | CAN1_L|
| **W3** | Default| **Pin 3** | 2| CAN1_H|
| **W4** | Default| **Pin 4** | 1 | 12V|

#### 5. Assembly Instructions
1.  **Prep:** Cut wires to length and strip insulation per Section 3.
4.  **Populate A:** Insert contacts into Connector A housing. *Verify "Click" and perform pull-back test.*
---

#### 6. Installation & Routing (Vehicle Integration)
*Instructions for the technician installing this harness into the chassis.*

* **Source Connection:** Main PCB, J49
* **Destination Connection:** Front Radar
* **Routing Path:**
    * Path - Right side top plate entry to bottom plate
    * Constraint - other cables
    * Fixing - Zip tie in red



## HAR-0018 HM30 Power
| **FROM** | **TO**  |
| ---| --- |
| Main_PCB J14|HM30 PWR |

#### 1. Nailboard

HAR-018 Nail Board

#### 2. Bill of Materials (Kitting)
*Gather these parts before starting the build.*

| Item Type | Part Number | Description / Spec | Qty Needed |
| :--- | :--- | :--- | :--- |
| **Connector A** | XT30-M| 2-Pos XT-30| 1 |
| **Terminals A** | Wire | Solder | 2|
| **Wire** | 16 AWG | Silicon | 170mm |
| **Sleeving** | Optional| Mesh|  xx mm|

#### 3. Wire Prep (Cut & Strip)
*Prepare all wires before assembly.*

| Wire ID | Color | Gauge | Cut Length | Strip A  | Strip B  |
|:--- |:----- |:--- |:--- |:--- |
| **W1**  | Red | **Pin 1** | 185 | 10 |
| **W2**  | Black | **Pin 2** | 185 | 10 |

#### 4. Termination & Pinout Map
*Connect End A to End B following this chart.*

| Wire ID | Color | From: 1704857  | To: Spade | Function / Signal |
| :--- | :--- | :--- | :--- | :--- |
| **W1** | Red | **Pin 1** | 1 | 12V |
| **W2** | Red | **Pin 2** | 2 | GND |

#### 5. Assembly Instructions
1.  **Prep:** Cut wires to length and strip insulation per Section 3.
3.  **Solder Side A:** Solder cables into housing.
---

#### 6. Installation & Routing (Vehicle Integration)
*Instructions for the technician installing this harness into the chassis.*

* **Source Connection:** Main_PCB, J27
* **Destination Connection:** ESC 1 PWR
* **Routing Path:**
    * Path - Right side top plate opening
    * Constraint - N/A
    * Fixing - N/A

 

## HAR-0019 -> HAR-0020 HM30 Signal
| **FROM** | **TO**  |
| ---| --- |
| Main_PCB J15|HM30 UART |
| Main_PCB J17|HM30 SBUS |

#### 1. Nailboard

HAR-019 Nail Board

HAR-020 Nail Board

#### 2. Bill of Materials (Kitting)
*Gather these parts before starting the build.*

| Item Type | Part Number | Description / Spec | Qty Needed |
| :--- | :--- | :--- | :--- |
|**4 Pin JST Cable** | N/A| JST, GH Connector Housing, 1.25mm Pitch, 4 Way| 1 |
|**3 Pin JST Cable** | N/A| JST, GH Connector Housing, 1.25mm Pitch, 3 Way| 1 |
| **Sleeving** | Optional| Mesh|  xx mm|

#### 3. Wire Prep (Cut & Strip)
*Prepare all wires before assembly.*

Pre-made JST-GH cables. No crimping required — source cables at the required lengths below.

| Harness | Connector | Required Length (mm) |
| :--- | :--- | :--- |
| HAR-019 (HM30 UART) | JST-GH 4P | 170 |
| HAR-020 (HM30 SBUS) | JST-GH 3P | 160 |

#### 4. Termination & Pinout Map
*Connect End A to End B following this chart.*

| Wire ID | Color | From: J15| To: HM30 UART| Function / Signal |
| :--- | :--- | :--- | :--- | :--- |
| **W1** | Default| **Pin 1** | 1| TX|
| **W2** | Default| **Pin 2** | 2| RX|
| **W1** | Default| **Pin 1** | 3| GND|
| **W2** | Default| **Pin 2** | 4| X|

| Wire ID | Color | From: J17| To: HM30 SBUS| Function / Signal |
| :--- | :--- | :--- | :--- | :--- |
| **W1** | Default| **Pin 1** | 1| IO_PPM_INPUT_AND_SBUS_INPUT|
| **W2** | Default| **Pin 2** | 2| GND|
| **W1** | Default| **Pin 1** | 3| x|

#### 5. Assembly Instructions
N/A

---

#### 6. Installation & Routing (Vehicle Integration)
*Instructions for the technician installing this harness into the chassis.*

* **Source Connection:** Bat_PCB J15, J17
* **Destination Connection:** HM30
* **Routing Path:**
    * Path - Right side top plate opening
    * Constraint - other cables
    * Fixing - Zip ties

    

## HAR-0021 -> HAR-0022 Navigation
| **FROM** | **TO**  |
| ---| --- |
| Main_PCB J7|F9P |
| Main_PCB J9|Mateksys |

#### 1. Nailboard

HAR-021 Nail Board

HAR-022 Nail Board

#### 2. Bill of Materials (Kitting)
*Gather these parts before starting the build.*

| Item Type | Part Number | Description / Spec | Qty Needed |
| :--- | :--- | :--- | :--- |
|**4 Pin JST Cable** | N/A| JST, GH Connector Housing, 1.25mm Pitch, 4 Way| 2 |
| **Sleeving** | Optional| Mesh|  xx mm|

#### 3. Wire Prep (Cut & Strip)
*Prepare all wires before assembly.*

Pre-made JST-GH cables. No crimping required — source cables at the required lengths below.

| Harness | Connector | Required Length  |
| :--- | :--- | :--- |
| HAR-021 (F9P / Here4) | JST-GH 4P | 205mm |
| HAR-022 (Mateksys) | JST-GH 4P | 70mm  |

#### 4. Termination & Pinout Map
*Connect End A to End B following this chart.*

| Wire ID | Color | From: J9| To: M9N| Function / Signal |
| :--- | :--- | :--- | :--- | :--- |
| **W1** | Default| **Pin 1** | 1| GND|
| **W2** | Default| **Pin 2** | 2| CAN1_L|
| **W3** | Default| **Pin 1** | 3| CAN1_H|
| **W4** | Default| **Pin 2** | 4| 5V|

| Wire ID | Color | From: J7| To: F9P| Function / Signal |
| :--- | :--- | :--- | :--- | :--- |
| **W1** | Default| **Pin 1** | 1| GND|
| **W2** | Default| **Pin 2** | 2| CAN1_L|
| **W3** | Default| **Pin 1** | 3| CAN1_H|
| **W4** | Default| **Pin 2** | 4| 5V|

#### 5. Assembly Instructions
N/A

---

#### 6. Installation & Routing (Vehicle Integration)
*Instructions for the technician installing this harness into the chassis.*
* **Source Connection:** Main_PCB J7, J9
* **Destination Connection:**  F9P/Here 4, Mateksys
* **Routing Path:**
    * Path - Immediately to the right
    * Constraint - N/A
    * Fixing - N/A

  

## HAR-0023 -> HAR-0025 PPP2ETH
| **FROM** | **TO**  |
| --- | --- |
| Main_PCB J35 | PPP2ETH |
| Main_PCB J36 | PPP2ETH |
| Main_PCB J41 | PPP2ETH |

#### 1. Nailboard

HAR-023 Nail Board

HAR-024 Nail Board

HAR-025 Nail Board

#### 2. Bill of Materials (Kitting)
*Gather these parts before starting the build.*

| Item Type | Part Number | Description / Spec | Qty Needed |
| :--- | :--- | :--- | :--- |
|**4 Pin JST Cable** | N/A| JST, GH Connector Housing, 1.25mm Pitch, 4 Way| 1 |
|**5 Pin JST Cable** | N/A| JST, GH Connector Housing, 1.25mm Pitch, 5 Way| 1 |
|**6 Pin JST Cable** | N/A| JST, GH Connector Housing, 1.25mm Pitch, 6 Way| 1 |
| **Sleeving** | Optional| Mesh|  xx mm|

#### 3. Wire Prep (Cut & Strip)
*Prepare all wires before assembly.*

Pre-made JST-GH cables. No crimping required — source cables at the required lengths below.

| Harness | Connector | Required Length  |
| :--- | :--- | :--- |
| HAR-023 (PPP2ETH CAN) | JST-GH 4P | 120mm |
| HAR-024 (PPP2ETH Ethernet) | JST-GH 5P | 205mm |
| HAR-025 (PPP2ETH UART) | JST-GH 6P | 155mm |

#### 4. Termination & Pinout Map
*Connect End A to End B following this chart.*

| Wire ID | Color | From: J35| To: PPP2ETH| Function / Signal |
| :--- | :--- | :--- | :--- | :--- |
| **W1** | Default| **Pin 1** | 1| 5V|
| **W2** | Default| **Pin 2** | 2| CAN2_L|
| **W3** | Default| **Pin 3** | 3| CAN2_H|
| **W4** | Default| **Pin 4** | 4| GND|

| Wire ID | Color | From: J7| To: PPP2ETH| Function / Signal |
| :--- | :--- | :--- | :--- | :--- |
| **W1** | Default| **Pin 1** | 1| ETH_RX+|
| **W2** | Default| **Pin 2** | 2| ETH_RX-|
| **W3** | Default| **Pin 3** | 3| GND|
| **W4** | Default| **Pin 4** | 4| ETH_TX+|
| **W5** | Default| **Pin 5** | 5| ETH_TX-|

| Wire ID | Color | From: J7| To: PPP2ETH| Function / Signal |
| :--- | :--- | :--- | :--- | :--- |
| **W1** | Default| **Pin 1** | 1| 5V|
| **W2** | Default| **Pin 2** | 2| UART5_RX_TEL2|
| **W3** | Default| **Pin 3** | 3| UART5_TX_TEL2|
| **W4** | Default| **Pin 4** | 4| UART5_CTS_TEL2|
| **W5** | Default| **Pin 5** | 5| UART5_RTS_TEL2|
| **W6** | Default| **Pin 6** | 6| GND|

#### 5. Assembly Instructions
N/A

---

#### 6. Installation & Routing (Vehicle Integration)
*Instructions for the technician installing this harness into the chassis.*

* **Source Connection:** Main_PCB J35, J36, J41
* **Destination Connection:**  PPP2ETH
* **Routing Path:**
    * Path - Direct connections. HAR024 will be routed under PPP, Beacon mounting board
    * Constraint - PPP,Beacon mounting board
    * Fixing - zip tie in red (HAR024)

 

## HAR-0026 Remote ID

| **FROM** | **TO**  |
| ---| --- |
| Main_PCB J20|Remote ID CAN |

#### 1. Nailboard

HAR-026 Nail Board

#### 2. Bill of Materials (Kitting)
*Gather these parts before starting the build.*

| Item Type | Part Number | Description / Spec | Qty Needed |
| :--- | :--- | :--- | :--- |
|**4 Pin JST Cable** | N/A| JST, GH Connector Housing, 1.25mm Pitch, 4 Way| 1 |
| **Sleeving** | Optional| Mesh|  xx mm|

#### 3. Wire Prep (Cut & Strip)
*Prepare all wires before assembly.*

Pre-made JST-GH cable. No crimping required — source cable at the required length below.

| Harness | Connector | Required Length  |
| :--- | :--- | :--- |
| HAR-026 (Remote ID) | JST-GH 4P | 65mm |

#### 4. Termination & Pinout Map
*Connect End A to End B following this chart.*

| Wire ID | Color | From: J20| To: RID| Function / Signal |
| :--- | :--- | :--- | :--- | :--- |
| **W1** | Default| **Pin 1** | 1| 5V|
| **W2** | Default| **Pin 2** | 2| CAN1_L|
| **W3** | Default| **Pin 3** | 3| CAN1_H|
| **W4** | Default| **Pin 4** | 4| GND|

#### 5. Assembly Instructions
N/A

---

#### 6. Installation & Routing (Vehicle Integration)
*Instructions for the technician installing this harness into the chassis.*

* **Source Connection:** Main_PCB J20
* **Destination Connection:**  RID
* **Routing Path:**
    * Path - Direct connection
    * Constraint - N/A
    * Fixing - N/A

 

## HAR-0027 SIYI Camera
| **FROM** | **TO**  |
| ---| --- |
| HM30 LAN & PWR|A8 PWR |
| HM30 LAN & PWR|A8 Video & Protocol |

#### 1. Nailboard

HAR-027 Nail Board

#### 2. Bill of Materials (Kitting)
*Gather these parts before starting the build.*

| Item Type | Part Number | Description / Spec | Qty Needed |
| :--- | :--- | :--- | :--- |
|**4 Pin JST Cable** | N/A| JST, GH Connector Housing, 1.25mm Pitch, 4 Way| 1 |
|**8 Pin JST Cable** | N/A| JST, GH Connector Housing, 1.25mm Pitch, 6 Way| 1 |
| **Sleeving** | Optional| Mesh|  xx mm|

#### 3. Wire Prep (Cut & Strip)
*Prepare all wires before assembly.*

Pre-made JST-GH cables. No crimping required — source cables at the required lengths below.

| Harness | Connector | Required Length  |
| :--- | :--- | :--- |
| HAR-027 power (4P) | JST-GH 4P | 325mm |
| HAR-027 video (8P) | JST-GH 8P | 325mm |

#### 4. Termination & Pinout Map
*Connect End A to End B following this chart.*

| Wire ID | Color | From: HM30 LAN & PWR| To: A8 PWR| Function / Signal |
| :--- | :--- | :--- | :--- | :--- |
| **W1** | Default| **Pin 1** | 1| 12V|
| **W2** | Default| **Pin 1** | 2| 12V|
| **W3** | Default| **Pin 2** | 3| GND|
| **W4** | Default| **Pin 2** | 4| GND|

 <br>

| Wire ID | Color | From: HM30 LAN & PWR| To: A8 Vid| Function / Signal |
| :--- | :--- | :--- | :--- | :--- |
| **W1** | Default| **Pin 3** | 3| ETH_TX+|
| **W2** | Default| **Pin 4** | 4| ETH_TX-|
| **W3** | Default| **Pin 5** | 5| ETH_RX+|
| **W4** | Default| **Pin 6** | 6| ETH_RX-|

#### 5. Assembly Instructions
N/A

---

#### 6. Installation & Routing (Vehicle Integration)
*Instructions for the technician installing this harness into the chassis.*

* **Source Connection:** HM30 LAN & PWR
* **Destination Connection:**  SIYI A8
* **Routing Path:**
    * Path - Right side middle plate opening to underside of bottom plate
    * Constraint - Other cables
    * Fixing - Undecided zip ties

  

## HAR-0028 Antenna
| **FROM** | **TO**  |
| ---| --- |
| Antenna 1|HM30 |
| Antenna 2|HM30 |

#### 1. Nailboard

HAR-028 Nail Board

#### 2. Bill of Materials (Kitting)
*Gather these parts before starting the build.*

Pre made cables with SMA connector. Length adjustment not required.

#### 3. Wire Prep (Cut & Strip)
N/A

#### 4. Termination & Pinout Map
N/A

#### 5. Assembly Instructions
N/A

---

#### 6. Installation & Routing (Vehicle Integration)
*Instructions for the technician installing this harness into the chassis.*

* **Source Connection:** Antenna
* **Destination Connection:** HM30
* **Routing Path:**
    * Path - Through enclosure provisions to middle plate
    * Constraint - N/A
    * Fixing - N/A



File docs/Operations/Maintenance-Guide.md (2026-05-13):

---
title: Maintenance Guide
sidebar_label: Maintenance Guide
sidebar_position: 3
---

# Maintenance Guide

Quiver Dev-Kit
Heavy-Lift Multipurpose UAV (<25 kg MTOW)

Table of content
[toc]

## 1. General Maintenance Principles

Maintenance operations are essential to discover potential issues within aircraft subsystems, reduce failure rates, and ensure the aircraft operates at peak performance. Regular maintenance is also critical for ensuring the aircraft can adapt to extreme mission environments. 

If a technician lacks the necessary tools or confidence to perform a specific maintenance operation, starting with a detailed visual observation is a valid best practice. Always share findings with the team or professional maintenance personnel before attempting repairs.

## 2. Subsystems Maintenance Checklist

Each subsystem affects the necessary functions, performance, and safety of the aircraft. 
Maintenance personnel should pay attention to the specific components listed below:

### 2.1. Motor Arm Assembly

| Component | Inspection Check | Potential Risk |
| :--- | :--- | :--- |
| **Propellers** | Check for cracks, fractures, or surface burrs. | Harmful vibration; cracks may spread leading to a crash. |
| **Propeller Clamp** | Ensure screws are tight and secure. | Vibration; risk of propeller falling off. |
| **Integrated Motor** | Check rotor case for cuts, notches, or deformation. | Coil damage, overheating, or fire risk due to stator collision. |
| **Motor Mount** | Verify arm mounting slot screws are tight. | Motor unit tilting causing unstable flight performance. |
| **Arm Connectors** | Check folding joint screws for play / looseness. | Harmful vibration and reduced flight stability. |
| **Arm Tube** | Inspect Carbon Fiber for cracks, fractures, or burrs. | Tube breakage during high-stress maneuvers. |

### 2.2. Cockpit Structure Assembly

| Component | Inspection Check | Potential Risk |
| :--- | :--- | :--- |
| **Structural Fasteners** | Check general airframe screws for tightness. | General structural integrity loss. |
| **Main Enclosure** | Verify screw tightness and overall case integrity. | Structural failure or component exposure. |
| **Top Lid** | Check hinge movement and latch security. | Lid opening in flight. |
|**Attachment Interface**|Check for wearing, contamination and pogo pin spring tension.|Unstable attachment equipment connection and controlling.|
| **Battery Interface** | Inspect latch slot for cracks or deformation. | Battery falling off; difficult insertion causing insecure locking. |
| **Battery Bay** | Check slide rails for dust, grease, or cracks. | Battery shifting in flight; difficult insertion or power loss. |
| **Battery Connector Cut-Out** | Check for deformation around the connector opening. | Poor electrical connection; invisible overheating signs. |

### 2.3. Electrical Components

| Component | Inspection Check | Potential Risk |
| :--- | :--- | :--- |
|**PCB Connectors**|Inspect for loose and contaminated connectors.|Short circuit or unstable connection lead to system failure.|
| **External Sensors** | Check mounts for cracks or loose screws. | Sensor tilting causing Flight Control errors or camera malfunction. |
| **Sensor Cabling** | Ensure cables are tight and not blocking sensors. | Obstruction of critical sensors. |
| **Battery Power Connector** | Inspect for dust, debris, or pitting on pins. | Reduced lifespan, short circuits, or total power loss. |
| **Battery Latch** | Check for broken latches or lost spring tension. | Battery shifting during maneuvers leading to power loss. |
|**Battery Pack Voltage**|Verify cell balance and total voltage.| Permanent damage to the battery. |

## 3. Tools Requirement

There is generally no strict requirement on tool brands for maintenance operations, but using tools with correct specifications and high quality helps extend the life of flight equipment. 

:::warning
**WARNING :**
Always acknowledge the user manual before using your tools.
:::

### 3.1. Always-prepared Items

The Quiver Dev-kit is a complex system that may encounter various configurations in the field. The following tools are recommended to be carried at all times during flight operations:

| Item | Requirement | Purpose |
| :--- | :--- | :--- |
| **Pliers** | Narrow / Thin | Modifying cables, connectors, and nuts in tight locations. |
| **Backup Propellers** | Full set (CW & CCW) | On-site repair for potential propeller damage. |
| **Hex Wrench Set** | L-Shape, Metric, Ball-end | Accessing fasteners in both open and narrow locations. |
| **Zip Ties** | ≈ 20 cm, medium flexibility | Wiring and cable harness management. |
| **Brush** | Non-conductive fiber | Safely cleaning electronic components. |
| **Rag / Paper Towels** | Lint-free | Cleaning grease or water drops. |
| **Personal Device** | PC / Tablet, USB-C cable | Ground diagnostics and configuration software. |

:::info
**REMINDER:**
For fastener tools such as hex wrench, confirm with the "Structural Assembly Guide" document or other user manual from equipment suppliers for the correct size and parameters.
:::

### 3.2. Additional Items

In addition to the field kit, the following things are **recommended** for the maintenance base to perform deeper level of cleaning, maintenance, and diagnostics.

#### 3.2.1. Devices

|Item|Requirement|Purpose|
|-|-|-|
|**More brushes**|Non-conductive fiber, Different sizes|Cleaning narrow locations.|
|**Compressed air device**| Pressure limitation|High efficiency dusting.|
|**Multimeter**|Digital display|Voltage and continuity inspection.|
|**DC power supply**| Adjustable Voltage | Powering up individual subsystems for analysis.|
#### 3.2.2. Fasteners & Consumable

|Item|Requirement|Purpose|
|-|-|-|
|**Screws**|-|(According to "Structural Assembly Guide" and equipment documents)|
|**Electrical tape**|-|Protecting exposed electrical connections.|
|**Velcro band**|-|Temporarily equipment and cable fixing.|
|**Adhesives**|Non-corrosive, Acid-free|Fixing any potential enclosure fracture.|

## 4. Regular Maintenance

This chapter provides a workflow for regular in-base maintenance. This procedure helps discover and record potential malfunctions and can be performed by personnel with basic training.

:::warning
**WARNING :**
For safety, the flight battery must be **removed** before starting the maintenance procedure.
:::

:::danger
**DANGER :**
Carbon fiber splinters can cause penetrating injuries. If you suspect a crack in carbon parts, use protective gloves or a cloth when handling.
:::

1. **Assembly & Extension:**
    - Check necessary frictions of landing gear insertion.
    - Check for loose screws on arm folding mechanisms.
    - Ensure proper operating clearance of the arm folding mechanism.
    - Check friction and security of telemetry antennas.
2. **Cockpit Structure Visual Inspection:**
    - Check for deformation, cracks or deep scratches.
    - Tap on different surfaces to discover any loose fasteners.
    - Check the connections of hinges and latches.
3. **Propulsion System:**
    - Extend propellers to the straightened position.
    - Check for loose fasteners on the thrust unit (motor).
    - Visual inspect for any propeller fractures or cracks.
    - Gently run a finger along propeller edges to detect burrs or chips.
4. **Internal Inspection:**
    - Open the cockpit lid gently.
    - Check lid hinge and latch fastening integrity.
    - Check mating quality between lid and main enclosure.
    - Inspect PCBs and Flight Controller for cleanliness.
    - Gently touch cables to check tension and connection security.
5. **Logging:**
    - Add a record to the maintenance log (Time, Issue Location, Status, Tools Used).
    - Photo or imagery are recommended.
    - Note them to a record. 
    - Report significant findings to professional engineering personnel.

### 4.1. Before & After flight

**Before Flight (Pre-Mission)**
* Perform visual inspection of aircraft shape and texture.
* Verify arm locking mechanisms are secure.
* Ensure payload interface is in good condition.

**After Flight (Post-Mission)**
* Perform visual inspection for new scratches or stress marks.
* Wipe down optical sensors (LiDAR/Radar).

### 4.2. Environment conditions 

For flight missions in harsh environment, extra maintenance steps are required.

1. Full power shutdown and remove the battery.
2. Wipe the remaining drops as clean as possible.
3. Check and clean gimbal camera and cockpit.
4. Follow the table below :

| Condition | Additional Measures |
| :--- | :--- |
| **Rain / Snow** | Leave the aircraft in a non-condensing, air-conditioned area to dry completely. |
| **Dust** | Perform compressed air dust removal on PCBs, motors, and attachment interfaces. |
| **Chemicals** | Perform decontamination on handling surfaces before transporting the aircraft. |

:::warning
**WARNING :**
If you discover water drops in the cockpit, that indicates the current flight condition exceeds the waterproof design level. Pause operations and wait for stable weather.
:::

### 4.3 Hour cycles maintenance

Operational stressors and environmental factors inevitably degrade aircraft components over time, increasing mechanical load and reducing safety margins. As a quadcopter platform, the Quiver Dev-Kit’s durability is primarily challenged by thrust-induced vibrations, acceleration forces, and environmental exposure.

The following checks should be performed at specific intervals:

| Flight Hours | Maintenance Items |
| :--- | :--- |
| **8 Hours** | Soft cleaning of cockpit inner space. |
| | Soft cleaning of battery connector and slide rails. |
| **24 Hours** | Rigidness check of PCB connectors and fasteners. |
| | Dusting of PCB and connectors. |
| | Check fasteners on thrust units and propellers. |
| | Calibrate Flight Controller IMU / Inertia sensors. |
| **50 Hours** | Check fasteners for external devices (e.g., Attachment Interface). |
| | Detect airframe structural deformation using a scale/straight edge. |
| | Partial disassembly for detailed inspection and cleaning. |
| | Inspect shock absorption and rubber components. |
| | Test battery connector contact resistance. |

:::warning
**WARNING :**
Excessive cleaning or plugging/unplugging of electrical connectors may decrease their cycle life. Clean only when necessary.
:::

## 5. Troubleshooting & Unscheduled Maintenance

Always be prepared for unexpected cases to minimize downtime and damage.

### 5.1. Abnormal behavior

Given the variability of flight missions and environmental conditions, the aircraft may occasionally exhibit irregular behavior. These anomalies can range from temporary glitches resolvable on-site to substantial issues indicating long-standing malfunctions. Correctly identifying the severity of these behaviors is critical for maintaining aviation safety and operational efficiency.

Here are some examples : 

| Behavior | Potential Cause | Solution | Result |
| :--- | :--- | :--- | :--- |
| **Heavy friction in joints** | Environmental particles (dust/sand). | Clean and lubricate (if applicable). | Friction returns to normal. |
| **Difficult battery insertion** | Connector or casing deformation. | Inspect battery and bay. | Repair or replace battery/rails. |
| **Top lid won't close** | 3D part deformation or cable pinch. | Inspect with flashlight while closing. | Reroute cable or adjust hinge. |
| **Excessive Vibration** | Unbalanced prop or loose arm. | Check props and arm bolts. | Flight becomes smooth. |
|...|...|...|...|

**Specific Component Diagnostics:**

* **Loose or Cracked Parts:**
    * **Visual Deformation:** If metal parts are bent, decommission immediately. If 3D printed parts show stress whitening or layer separation, replace.
    * **Surface Feel:** If a surface feels rough or "glitchy" (delamination), inspect closer.
    * **Friction Loss:** If a folding joint loses friction, tighten the tension screw. If a 3D printed joint is worn loose, replace the part.

* **Irregular Response:**
    * **Sound:** Cracking sounds indicate structural stress; grinding sounds indicate motor bearing failure.
    * **Takeoff Vibration:** Often caused by a loose fastener in the arm system.
    * **Overheating:** Electronics getting hot quickly may indicate a short circuit or bad connection. Note that motors naturally get warmer in summer.

### After impact & accident inspection list

#### Hard or failed landing

Any landing with an unsafe touchdown maneuver is considered a **Hard Landing**. If the aircraft suffers major damage, it is a **Crash**.

| Incident Level | Inspection Scope |
| :--- | :--- |
| **Heavy Landing** | **1. Landing Gear:** Check for cracks in mounts or tubes. |
| *(About to bounce)* | **2. Mission Attachments:** Verify security and pogo-pin connection. |
| | **3. Battery:** Check insertion alignment and connector integrity. |
| **Turn Over / Flip** | **1. Propellers & Motors:** Check for chips, bent shafts, or gravel in bells. |
| *(Props touched ground)* | **2. Motor Arms:** Check carbon tubes for crushing/cracking. |
| | **3. Arm Connectors:** Verify folding mechanism isn't bent. |
| | **4. Plates:** Check central chassis for twisting. |
| **Crash / Terrain Impact** | **1. Full Structural Audit:** All of the above. |
| | **2. 3D Printed Parts:** Check for shattering or layer split. |
| | **3. Flight Controller:** Re-calibrate IMUs; check isolation dampers. |
| | **4. Decommissioning:** Assess if repair cost exceeds replacement. |

**Tree Collision Specifics:**

* **Foliage (Leaves):** Check propellers for green stains/chips; check 3D printed parts for impact marks.
* **Branches:** Check external sensor cables and antennas for cuts/tears.
* **Stuck in Plant:** Consider as a full crash; perform full audit.

## 6. Remarks

This maintenance guide is a living document and may be updated based on flight experience and technical advancements.

*(End of content)*

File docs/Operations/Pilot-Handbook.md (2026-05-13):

---
title: Pilot Handbook
sidebar_position: 1
---

# Pilot Handbook
Quiver Dev-Kit
Heavy-Lift Multipurpose UAV (<25 kg MTOW)

<!-- Table of content -->
<!-- [toc] -->

## 1. Safety & Compliance

### 1.1 General Safety Principles
The Quiver Dev-Kit is a battery powered heavy-lift quadcopter (MTOW ~25kg). It is engineered for industrial aerial applications. It is **not** designed for the deployment of munitions/explosives, or critical life-support transport.

> [!CAUTION]  
>
> Any improper or reckless action can result in:
> 
> - Immediate fatality or severe permanent injury.
> - Electrical or metal fire hazards (Class C & D).
> - Property damage.
> - False public alert, panic or unnecessary crowds.
> - Noise pollution or disruptions.
> - Legal liability and reputational damage.

All operators must be trained and familiar with the aircraft and local aviation regulations. The Pilot in Command (PIC) must remain alert and strictly adhere to the **IMSAFE** protocol (Illness, Medication, Stress, Alcohol, Fatigue, Emotion) before operations.

### 1.2 Operational Limits
#### 1.2.1 Weather Conditions
**Wind Speed**:
Maximum sustained wind speed is 15 knots (approx. 28 km/h) and wind gusts up to 18 kts (approx. 33 km/h). Gusts exceeding this limit may compromise stability.

**Solar Activity**:
Monitor Kp Index and UV Intensity via pre-flight forecast. High UV indices can degrade composite materials over time, and high Kp (>4) can interfere with GNSS reliability.

**Precipitation**:
While the fuselage features some water-resistant seals, flight in rain, snow, or hail is prohibited for the Dev-Kit drone.

**Temperature**:
Ambient Air: Operating range is -10°C to +35°C.
Battery Temp: Do not operate if battery core temperature exceeds 56 °C. Land immediately if this threshold is reached.
      
#### 1.2.2 Visual Line of Sight (VLOS):
The Pilot in Command (PIC) must maintain effective Visual Line of Sight at all times, unaided by binoculars or FPV goggles.

Regulatory References:

- EU (EASA): Operations must comply with Open Category A3 requirements (fly far from people) unless a Specific Category authorization (SORA/PDRA) is held.
- USA (FAA): Operations must comply with 14 CFR Part 107.31 (Visual Line of Sight Aircraft Operation).

#### 1.2.3 Airspace Restrictions:
- EU: Consult national geographical zones (e.g., dipul in Germany, Geoportal in France).
- USA: Use B4UFLY or FAA DroneZone to verify airspace authorization (LAANC).

#### 1.2.4 EASA & FAA Specifics (Weight Class <25 kg):
**EU (EASA)**:

Open Category A3, C3 class drone:
You may fly without a SORA if you maintain a minimum horizontal distance of 150 m from residential, commercial, industrial, or recreational areas and ensure no uninvolved people are endangered.

Specific Category:
If your mission requires flying closer than 150 m to populated areas or over people, you must obtain an operational authorization based on a SORA (Specific Operations Risk Assessment) or PDRA.

**USA (FAA)**:

You must hold a Remote Pilot Certificate (Part 107).

The aircraft must be registered with the FAA.

The aircraft must broadcast a RemoteID signal while in flight. 

Operations over human beings are prohibited unless complying with remote ID and kinetic energy limitations, which this aircraft (25 kg) generally exceeds without a specific waiver.

**Geo-Fencing**:

The pilot must establish a local geo-fence for every flight.

Setup: Configure the FENCE_RADIUS and FENCE_ALT_MAX in the ground station software to contain the drone within the authorized flight volume.

> [!WARNING]  
> 
> Geo-fencing relies on minimum GNSS. It may not function during a navigation system error or location source failure.

**Experimental Systems Disclaimer**:

Radar & LiDAR Altimeters: These sensors are currently integrated for testing purposes only.

Do not rely on these sensors for critical flight phases. The pilot must verify altitude visually and via barometric telemetry.

These systems may be activated for controlled testing only when there is zero risk to third parties, animals, or infrastructure.

**Instructions on how to find local regulations**:
...

### 1.3 Electrical Warning

#### 1.3.1 Arcing & Spark Risk
The electrical system is designed to be spark-free during connection via a pre-charge circuit.

> [!WARNING]  
> 
> If you observe any visible spark or audible "crack" when connecting the battery :
> - STOP immediately.
> - Disconnect and contact support.
> - Do not fly.
> 
> This indicates a failure in the pre-charge circuit or a short in the power system.

#### 1.3.2 Flight Battery Handling
**General Principles：**

> [!NOTE] 
> 
> The following principles apply to both battery and charger.

- Use only Tattu 3.5 or 4.0 14S Smart LiHV batteries.
- Use the official Tattu-supported charger compatible with 14S LiHV chemistry or SkyRC equivalent.
- Never short or ground the battery main connector even in non-operating condition.
- Minimize the unnecessary plug-and-unplug cycles to extend power connector life.
- Always check power connector cleanliness and dryness.
- Always keep a Class D fire extinguisher nearby (additional fire blanket are recommended).

**Charging:**
 
- Charge only in a designated dry, fire-resistant area (e.g., concrete floor), away from living quarters or flammable materials.
- Never charge a battery that significantly warmer than human body temperature or right after a fully-discharge flight. Allow it to cool down for 15 ~ 30 minutes before apply a charging current.

**Transport & Storage:**

- If the battery will not be used for next 14 Days, discharge it to storage voltage (3.80V per cell / approx. 50-60% capacity).
- Any battery dropped from any height > 50 cm is unsafe for flight. Internal damage is invisible and can cause unpredictable power outage or fires.
- Water vapor may condense on the battery surface when transferring from cold to hot environments. Allow it to acclimate and dry completely before connecting.

**In-Flight Emergency:**

> [!WARNING] 
> 
> To prevent escalating a failure, minimize aggressive maneuvers during any battery system emergency.
> - If battery temperature exceeds **56°C**, land immediately.
> - If voltage sags rapidly, oscillates abnormally, or stops updating, land immediately.

**Battery Fire Emergency**:

> [!CAUTION] 
> 
> In case of pungent gas, irregular popping sounds or smoke, **IMMEDIATELY:**
> - **Disconnect** the battery immediately (if safe to do so).
> - **Evacuate** the battery to an open outdoor area away from flammable materials (do not leave it in a corridor).
> - **Observe** from at least 15 meters away with a Class D fire extinguisher ready.

> [!CAUTION] 
> 
> In case of an **ACTIVE BATTERY FIRE** indoors:
> - **Evacuate** all personnel, order them to call emergency department as "Battery Fire".
> - **Cover** the battery with a fire blanket if the condition is still safe.
> - **Remove** proximate flammable objects as possible.
> - **Cut off** the main power supply.
> - **Exit** to an open area.

### 1.4 Establishing Safety Zones (Kinetic Energy)

The drone generates significant kinetic energy during flight. A free-fall impact from operational altitude carries lethal force, capable of penetrating vehicle roofs or causing fatal injury. Therefore, establishing a correct safety zone is the single most critical pre-flight step.

**Official Guidelines as Primary Source**
The Pilot in Command (PIC) must strictly adhere to the safety distances mandated by the local aviation authority. These regulations take precedence over any manufacturer recommendations:

- **EU (EASA)**: Operations fall under the Open Category A3. You must maintain a horizontal distance of at least 150 meters from residential, commercial, industrial, or recreational areas. You must never fly over uninvolved persons.

- **USA (FAA)**: Operations under Part 107 generally prohibit flight over human beings for drones of this weight class (Category 3/4) without a specific Declaration of Compliance or Waiver, due to the kinetic energy exceeding 25 ft-lbs limit.

**Operational Safety Zone Calculation (Ground Risk Buffer)**
To ensure no harm can come to any person or animal in the event of a complete power failure (ballistic fall), the pilot must establish a **Ground Risk Buffer**. This buffer extends beyond the intended flight path.

A widely accepted safety standard for rotary-wing aircraft is the 1:1 Rule:

> [!NOTE] 
> 
> Minimum Safety Buffer = Flight Altitude (AGL)

- **Example**: If flying at 50 meters (164 ft) altitude, you must ensure a clear zone of at least 50 meters horizontally from your flight path where no uninvolved persons are present.

- **Why?** If the drone loses power while moving at speed, momentum will carry it forward as it falls. The 1:1 rule provides a simplified safety margin to contain this ballistic trajectory.

**Implementation Steps**:

1. **Identify the Operational Volume**: Define the exact area where the drone will fly.

2. **Add the Buffer**: Extend this area by a distance equal to your maximum planned altitude (the 1:1 rule).

3. **Verify the Ground**: Ensure this entire extended zone is clear of non-participants, animals, and critical infrastructure.

4. **Geo-Fence**: Program the flight controller's Geo-Fence to prevent the drone from exiting the Operational Volume, ensuring that even if it hits the "virtual wall" and falls, it remains within the Ground Risk Buffer.

## 2. System Setup
### 2.1 Unbox and assemble
> [!TIP] 
> 
> Due to the large size of the aircraft, a two-person lift or assistance is recommended for assembly.

> [!WARNING] 
> 
> Be aware of pinch and cut.
> 
> Unlocked folding motor arms will rotate while horizontal force or unwise handling technique being applied.

**1. Preparation:**
- Reserve enough working space for transport case, devices and the aircraft assembly.

**2. Extraction:** 
- Lift the aircraft by the central aluminum airframe with symmetrical handling. 
- Never lift by the avionics lid, plastic or 3D-printed parts.

**3. Landing gear assembly:**
- Steadily holding the aircraft.
- Fully insert the detached landing gear tube into the quick-release joint. 
- Rest the aircraft on flat surface.
- Fully tighten the quick-release screw.
- Confirm the installation by applying a light pull on the landing gear component.

**4. Extend motor arms**
- Check the contact section of arm folder for any obstacles.
- Unfold and fully align one motor
- Rotate and fully engage the lock handle.
- Visually verify the locking mechanism is engaged and immobile.
- Repeat steps above for all remaining motor arms.

**5. Antenna assembly:**
- Unfold and extend both antenna to upright.
- Check and tighten antenna connector.
- Rotate and adjust the antennas to a heading where they do not face each other.

**6. Gimbal camera assembly:**
- Check the integrity of cables, connectors and rubber damper balls.
- Remove any camera protection or locking mechanism before power up.
- Check for dust and debris at lens and gimbal motor gaps and apply proper cleaning.

### 2.2 Installing battery
> [!NOTE] 
> 
> Acknowledge the "Flight Battery Handling" chapter before handling the battery.

> [!WARNING] 
> 
> During the following steps:
> - Do not power on the battery.
> - Do not press the battery power button right after the installation.

1. Align the battery to the 3D-printed guide rails with the connector side up. 
2. Insert the battery by sliding it into the aluminum chassis.
3. Secure the mechanical latch and check the lock position.
4. Confirm the battery is locked in place by applying a light pull on the lift handle.

### 2.3 Battery power button 

**For Tattu 3.5 series:**
- There is always voltage present at the battery terminals. The 3.5 Tattu smart batteries do not offer the function to control the battery power output.
- The power button can be used to display the charging state or to awake the internal CAN bus communication of the battery.

**For Tattu 4.0 series:**
- The power button can be used to control the battery power up state. The output needs to be activated before the push button on the drone can power up the drone.
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

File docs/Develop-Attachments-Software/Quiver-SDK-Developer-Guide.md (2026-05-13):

# Quiver SDK Developer Guide

**Version:** April 2026

---

## 1. System Overview

Quiver Hub is a cloud-hosted web application that provides real-time visualization, remote management, and data logging for UAV operations. The companion computer (Raspberry Pi) runs Python services that bridge the flight controller, payload devices, and Hub over HTTPS and WebSocket. Operators interact through the Hub web UI; the companion computer handles all local hardware communication and data forwarding autonomously.
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

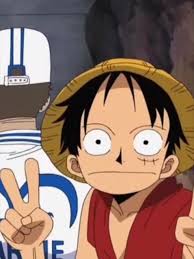
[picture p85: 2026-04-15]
docs/Manufacturing/Assembly-Guides/assets/images/Harnessing/placeholder.jpg

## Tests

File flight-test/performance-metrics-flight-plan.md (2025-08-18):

## Project Description  
This test plan defines a repeatable, quantitative framework for evaluating any two Project Quiver prototypes by measuring how their airframe, mass distribution, and sensor suites affect flight mechanics across seven performance domains: control & maneuverability, stability & oscillations, energy efficiency, vertical performance, yaw authority & heading stability, navigation accuracy, and aerodynamic effectiveness.

---

## Methodology  
All metrics derive from ArduPilot `.bin` flight logs processed via Mission Planner, MAVExplorer, PyMAVLink, and custom scripts. For each test:  
1. **Extract** the relevant channels (e.g. `RATE.*`, `IMU.*`, `BAT.*`, `CTUN.*`, `ATT.*`, `POS.*`)  
2. **Compute** RMS errors, response times, FFT peaks, power-to-thrust ratios, peak rates, waypoint deviations, etc., according to the recipes below  
3. **Visualize** results with time-series overlays, histograms, bar/line charts, FFT spectra, and map-scatter plots  

---

## Flight Tests & Pilot Directives

### 1. Control & Maneuverability  
- **Test:** From hover at 3 m AGL, perform:  
  - 5 pitch-rate steps of ±100 °/s  
  - 5 roll-rate steps of ±100 °/s  
  - 3 yaw-rate steps of ±90 °/s  
- **Directive:** Use guided mode or exact RC inputs to command precise steps; keep throttle constant.  

### 2. Stability & Oscillations  
- **Test:** Loiter (or AltHold) hover at 3 m AGL for 60 s.  
- **Directive:** Minimize stick inputs; maintain position within 1 m.  

### 3. Energy Efficiency  
- **Hover Endurance:** Hover at 3 m AGL until battery reaches 20 % reserve.  
- **Waypoint Mission:** Fly a square mission (e.g. 50 m × 50 m² at 5 m/s), land at mission end.  
  > ²Distances can be changed based on test-site limitations but must be identical for both prototypes.  

### 4. Vertical Performance  
- **Test:** From hover at 3 m, full-throttle climb to 10 m³ (repeat 3×).  
  > ³Altitudes can be adjusted to local airspace restrictions but must match between tests.  
- **Directive:** After reaching target, center sticks for level flight.  

### 5. Yaw Authority & Heading Stability  
- **Test:** Auto-mode circle of 20 m radius⁴ at 3 m/s for 3 laps.  
  > ⁴Radius customizable but identical across prototypes.  
- **Directive:** Upload a simple circular mission; observe drift and correction.  

### 6. Navigation Accuracy  
- **Test:** Auto mission through 5 waypoints forming a 60 m square, hover 5 s at each.  
- **Directive:** Ensure waypoint coordinates are entered precisely.  

### 7. Aerodynamic Effectiveness  
> _Perform only after structural sign-off._  
- **Deceleration Rate:** Cruise at 5 m/s, cut throttle, record deceleration.  
- **Glide Capability:** From 10 m, neutral throttle, measure time to 3 m AGL⁵.  
  > ⁵Start/end altitudes adjustable but consistent across tests.  

---

## Metrics & Calculations

| **Domain** | **Metric** | **Source** | **Calculation** |
|---|---|---|---|
| **Control & Maneuverability** | Rate Tracking Error (deg/s) | `RATE.R/P/YDes` vs. `RATE.R/P/Yout` | RMS & peak of `(Des−Out)` during rate steps |
| | Response Time (s) | same | Time to 90 % of step amplitude in `RATEOut` |
| | Overshoot (%) | same | `(max(RATEOut)−step)/step×100` |
| **Stability & Oscillations** | IMU Vibration RMS (m/s²) | `VIBE.X/Y/Z` or `IMU.AccX/Y/Z` | RMS of raw vibration data during hover |
| | Oscillation Frequency (Hz) | same | FFT of hover IMU data; dominant frequency peak |
| **Energy Efficiency** | Hover Throttle (%) | `RCOU.*` | Average servo output during steady hover |
| | Power-to-Thrust Efficiency (N/W) | `BAT.Curr`, `BAT.Volt`, mass | `(mass×g)/(Iavg×Vavg)` |
| | Flight Time (min) | takeoff/landing timestamps | Difference between airborne start and end |
| **Vertical Performance** | Max Climb Rate (m/s) | `CTUN.CRt` | Peak value during full-throttle ascent |
| | Thrust Margin (%) | `RCOU` hover throttle | `(1−hover_throttle)×100` |
| **Yaw Authority & Heading** | Yaw Tracking Error (deg) | `ATT.DesYaw` vs. `ATT.Yaw` | RMS and peak error during yaw steps and auto-turns |
| | Turn Coordination (deg) | `GPS.GCrs` vs. `ATT.Yaw` | Mean angular difference between ground track and heading |
| **Navigation Accuracy** | Waypoint Tracking Error (m) | `POS.X/Y` vs. waypoints | Euclidean distance at each waypoint arrival |
| | Yaw Misalignment (deg) | `ATT.Yaw` vs. velocity vector | Angular difference at waypoint arrivals |
| **Aerodynamic Effectiveness** | Deceleration Rate (m/s²) | `PSCN/PSCE Vel`, `CTUN.ThO` | Slope of velocity vs. time after throttle cut |
| | Glide Capability (s/m) | `PSCD Vel`, `CTUN.ThO` | Time/distance sustained at zero throttle until target altitude |

---

## Results & Deliverables  

| **Metric** | **Proto A** | **Proto B** | **Better** | **Notes** |
|---|---|---|---|---|
| Hover Throttle (%) | | | | |
| IMU Vibration RMS (AccZ, m/s²) | | | | Use `VIBE.Z` for consistency |
| FFT Peak Frequency (Hz) | | | | Hover FFT of AccZ |
| Rate Tracking RMS (deg/s) | | | | Average of pitch/roll/yaw errors |
| Response Time (s) | | | | 10–90 % rise time |
| Overshoot (%) | | | | Peak overshoot in rate steps |
| Power-to-Thrust (N/W) | | | | mass·g/(I×V) |
| Flight Time (min) | | | | Hover to 20 % battery |
| Max Climb Rate (m/s) | | | | Peak `CTUN.CRt` |
| Thrust Margin (%) | | | | (1–hover_throttle)×100 |
| Yaw Tracking Error (deg) | | | | RMS during auto-turn |
| Turn Coordination (deg) | | | | Mean heading vs. track error |
| Waypoint Error (avg, m) | | | | Mean radial error at waypoints |
| Yaw Misalignment at WP (deg) | | | | Mean across all waypoints |
| Deceleration Rate (m/s²) | | | | After throttle cut cruise |
| Glide Time (s) | | | | Time from start to end altitudes |

---

## Next Steps  
- Automate log processing to populate this table for each new prototype pair.  
- In later rounds, conduct back-to-back flights under identical PID settings to isolate airframe effects.  
- Use insights to guide structural, CG, and damping improvements for PTₙ.

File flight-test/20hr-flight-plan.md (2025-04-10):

# Project Quiver Prototypes 20-Hour Flight Test Plan  

###  Mission Objective
The multipurpose drone will carry a brush bullet dispenser and autonomously follow a predefined waypoint mission to deliver the payload (bullet) at specific coordinates. The test plan ensures system safety, flight performance, stability, and successful payload delivery.

---

## Test Plan Overview

| Phase | Flight Time |
|---|---|
| Payload Integration & Basic Handling | 3.0 hrs |
| PID Tuning & Stabilization | 4.0 hrs |
| Automated Mission & Dispensing | 4.0 hrs |
| Performance Envelope & Final Validation | 3.5 hrs |
| Emergency Handling & Failsafe | 2.0 hrs |
| **Total** | **20.0 hrs**|

## General Guidelines

- **Flight Controller**: Pixhawk with ArduPilot
- **Modes Used**: Stabilize, AltHold, PosHold, Loiter, Auto, RTL, Guided
- **Payload**: Brush Bullet Dispenser 
- **Logging**: Full logs including Ardupilot parameters as well as ESC and battery related ones

---

##  Phase 1: Payload Integration & Basic Handling (3.0 hours)

### Objective
Validate basic control and hover performance without the payload and with payload mounted. Observe any mechanical or control issues due to added weight.

### Pilot Instructions

- Ensure the dispenser is physically and electronically secured.
- Use conservative throttle inputs during initial hover.
- Activate the dispenser manually while on the ground before flight.

### Tests

| Test | Time | Description |
|---|---|---|
| Hover Tests (Stabilize mode) | 0.5 hr | Hover at various altitudes (1–5 m), observe drift, stability, power draw. |
| Translational Maneuvers | 0.5 hr | Move forward/backward/left/right in AltHold. Monitor response lag. |
| Yaw Control | 0.5 hr | Rotate CW/CCW. Evaluate smoothness and stability with payload. |
| Manual Dispenser Activation | 0.5 hr | Activate the dispenser while flying low. Ensure drone stability. |
| Hover + Payload Power Profile | 0.5 hr | Log current draw during hover with full payload weight. |
| Pre-Flight Logging | — | Monitor `RCOUT`, `CTUN.ThO`, `BATT.Curr`, `IMU`, and vibrations. |

###  Post-Flight
- Tune `ATC_ANG_PIT_P`, `ATC_RAT_PIT_P`, etc., if instability observed.
- Inspect vibration logs (`VIBE`, `IMU`).
- Ensure secure payload mounting after each flight.

---

## Phase 2: PID Tuning & Stabilization with Payload (4.0 hours)

### Objective
Optimize stability and responsiveness using PID tuning and assess control under different flight modes with the payload.

###  Pilot Instructions

- Begin with default gains and use Autotune.
- Maintain high altitude (5–10 m) to allow recovery.
- Focus on smooth transitions and yaw precision.

###  Tests

| Test | Time | Description |
|---|---|---|
| Autotune - Roll & Pitch | 1.0 hr | Use Autotune in calm conditions. Let ArduPilot adjust gains. |
| Manual Yaw PID Tuning | 1.0 hr | Observe yaw response. Adjust `ATC_RAT_YAW_P`, `D`, `FF` as needed. |
| Autonomous Loiter & Transitions | 1.0 hr | Fly in Loiter and AltHold. Check mode switching latency and stability. |
| Emergency Maneuvers | 1.0 hr | Try GPS loss (simulate) and RTL. Monitor failsafe smoothness. |

###  Post-Flight
- Analyze `ATT.Des*` vs `ATT.Act*` for accuracy.
- Review `RCOUT.*`, `BATT.Curr`, and `RATE.*` for responsiveness and control margin.

---

## Phase 3: Automated Waypoint Mission with Payload (4.0 hours)

### Objective
Test precise waypoint navigation and dispenser activation during autonomous missions.

###  Pilot Instructions

- Upload pre-planned waypoint mission with target coordinates.
- Include Do-Set-Servo commands for dispenser triggering.
- Ensure GPS HDOP < 1.5 before flight.

###  Tests

| Test | Time | Description |
|---|---|---|
| Full Auto Waypoint Mission | 1.5 hr | 6–10 waypoints with altitude changes and RTL. Monitor path accuracy. |
| Dispenser Activation During Mission | 1.0 hr | Trigger payload drop at designated waypoints. Observe altitude, GPS offset. |
| Dispensing Accuracy | 0.5 hr | Validate hit accuracy (visually or via ground markers). |
| Geofence & RTL Test | 0.5 hr | Trigger fence breach. Confirm automatic RTL activation. |

### 🔧 Post-Flight
- Check `NAV`, `CMD`, `CTUN.DSAlt`, Dispenser Relay
- Log hit accuracy per waypoint vs GPS logs.
- Verify mission repeatability with same path.

---

## Phase 4: Performance Envelope & Final System Validation (3.5 hours)

### Objective
Test operational performance under stress: payload, speed, long range, and dispensing under flight extremes.

### Pilot Instructions

- Use Auto mode for consistent paths.
- Stay within legal altitude and range limits.
- Be ready to switch to Stabilize in case of failure.

### Tests

| Test | Time | Description |
|---|---|---|
| Max Payload Flight | 1.0 hr | Fly at full load (bullet + dispenser). Check climb rate, power. |
| High-Speed Flight | 1.0 hr | Auto mode at 15–20 m/s. Monitor speed accuracy and vibration. |
| Long-Range Mission | 1.0 hr | Max distance with multiple waypoints and RTL. Track GPS errors. |
| Final Dispenser Activation | 0.5 hr | Drop payload at max speed and range. Ensure stability. |

###  Post-Flight
- Analyze current draw vs flight phase (`BATT`, `CTUN.ThO`).
- Assess path tracking (`POS.X`, `POS.Y`, `NAV`).
- Document hit accuracy, battery usage, temperature.

---

## Phase 5: Emergency Handling & Safety Tests (2.0 hours)

### Objective
Validate failsafe actions for GPS/RF/Battery failure while carrying a payload.

### Pilot Instructions

- Ensure logs are active before test.
- Test in open space with no GPS drift zones.
- Stay ready on transmitter to recover control manually.

### Tests

| Test | Time | Description |
|---|---|---|
| GPS Loss Simulation | 1.0 hr | Mask GPS or disconnect. Drone should switch to Land/Stabilize or return safely. |
| RC Signal Loss | 1.0 hr | Turn off transmitter. Ensure RTL or Land triggers. Verify it returns to Home and lands safely. |

### Post-Flight
- Check `FS_GPS`, `FS_GCS_ENABL`, `FS_THR` behavior in logs.
- Measure RTL timing and descent quality with payload.
- Log all emergency responses and recommend safety thresholds.

---

##  Notes & Deliverables

- Full flight logs (`.bin` or `.log`)
- Pilot logs and videos if available
- Dispenser test records (accuracy log)
- Tuning parameter snapshots (`.param`)
- Battery and ESC temperature records
- Dispenser system validation document

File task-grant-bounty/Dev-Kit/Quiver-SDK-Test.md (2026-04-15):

# Quiver SDK Test Information note

## Status

`Valid: True`

`Revision History: 2025-12-03 – Consolidated Arrow's unified payload/companion SDK discussion and RPLidar C1 terrain mapping documentation.  `

`Replacement Log: None – first canonical information-note for this effort.  `

`Reference: Forum topic “Exploring a Unified Payload and Companion Computer SDK for Quiver” (2025-10-31 onward) and the RPLidar C1 Terrain Mapping System documentation set (README, SETUP_GUIDE, QUICK_REFERENCE, DEPLOYMENT_CONFIG, SYSTEM_SUMMARY).`

---

## Project Description

This project explores and implements a concrete Minimum Viable Product (MVP) for a **unified payload and companion computer SDK for the Quiver UAV platform**, using an **RPLidar C1 terrain-mapping payload** as the primary reference case.

Within the broader Arrow DAO context, Quiver is evolving from a modular UAV into a general-purpose aerial robotics platform. The forum concept envisions:

- A **Payload and Companion Computer SDK** that allows third parties to integrate new sensors, actuators, and modules without modifying core firmware or reverse-engineering protocols.
- An SDK layered on top of **MAVLink/MAVSDK** and related open standards, providing predictable APIs, templates, and code patterns for both flight and payload integration.
- A development paradigm where Quiver is treated as a **“programmable aerial computer”**, enabling onboard applications, autonomous logic, and tight coupling between payloads, the companion computer, and ground control systems.

As an early concrete instantiation of this idea, the RPLidar C1 terrain mapping system demonstrates the **companion-computer-mediated integration path** described in the forum topic:

> (Payload: RPLidar C1 → Raspberry Pi) → (Attachment Interface: Ethernet TCP/UDP) → (Companion Computer: RPi 4/5 with 4G/5G module → HTTP POST) → (Web Portal: Simple Web Server → Simple live web visualization)

The documentation set provided (README, SETUP_GUIDE, QUICK_REFERENCE, DEPLOYMENT_CONFIG, SYSTEM_SUMMARY) describes a **production-ready implementation** of this pipeline:

- The **RPLidar C1** sensor captures 360° scans at ~10 Hz.
- A **Raspberry Pi** handles low-level serial I/O and streams accumulated point clouds via TCP.
- A **companion computer** receives these scans and forwards them to a web server over HTTPS.
- A **web server and browser client** visualize the point cloud in real time via WebSocket.

This implementation serves two primary purposes:

1. **Functional Payload Demonstrator** – Deliver a working end-to-end mapping solution with clear installation, configuration, and troubleshooting guidance.
2. **SDK Architecture Prototype** – Provide a concrete, well-documented example of how payloads, companion computers, and web interfaces can interoperate, informing the design of a generalized Quiver SDK for future payloads (e.g., cameras, rangefinders, flight telemetry displays).

---

## Methodology

### 1. System Architecture and Data Flow

The RPLidar terrain mapping system is structured as a **multi-node pipeline**:

1. **Payload Sensor Layer**
   - Hardware: **SLAMTEC RPLidar C1** lidar sensor.
   - Interface: USB serial, 460800 baud, 8N1.
   - Function: Continuous 360° distance measurements, with packets encoding quality, angle, and distance.

2. **Payload Processor / Edge Streamer (Raspberry Pi)**
   - Role: Dedicated node for real-time sensor interfacing and point cloud generation.
   - Responsibilities:
     - Connects to the RPLidar via `/dev/ttyUSB0` (configurable).
     - Executes the RPLidar C1 library to:
       - Set motor speed (typically 600 RPM).
       - Initiate scanning (`start_scan()`).
       - Accumulate full 360° scans before sending (ensuring dense, non-sparse point clouds).
     - Serializes each complete scan into JSON and streams scans over TCP to the companion computer.
   - Services:
     - `rplidar-streamer.service` (systemd) manages lifecycle and auto-start.
   - Data Format:
     - TCP payloads use a length-prefixed JSON format, carrying `timestamp`, `scan_id`, and an array of points with angle, distance, and quality.

3. **Companion Computer Forwarder**
   - Role: Network and compute hub closer to the Quiver flight controller, aligned with the Arrow DAO vision of a **companion-computer-centered SDK**.
   - Responsibilities:
     - Listens on a configurable TCP port (default 5555) for scan data from the Raspberry Pi.
     - Uses Python with `aiohttp` to forward scans via **HTTP POST** to a web server REST API.
     - Includes API key authentication via `X-API-Key` HTTP header.
     - Uses asynchronous I/O to maintain high throughput (10 Hz scan rate) with low latency (<200 ms).
   - Services:
     - `rplidar-forwarder.service` (systemd) manages the forwarder process and ensures automatic startup and restart.

4. **Web Server and Browser Visualization**
   - Web server provides:
     - REST endpoint `/api/rest/pointcloud/ingest` for ingesting point clouds.
     - WebSocket broadcast channel for pushing data to browsers.
     - A web-based interface (e.g., the referenced “RPLidar Terrain Mapping Visualization” and later the “Quiver Hub” interface) that renders the incoming point cloud in real time.
   - Browser:
     - Subscribes via WebSocket.
     - Renders 360° point clouds at ~10 Hz, showing terrain structure, obstacles, and environment.

This chain directly parallels the SDK architecture path described in the forum discussion and can be generalized for other payloads (camera feeds, flight attitude/position overlays, rangefinder-based visualizations, etc.).

### 2. Deployment and Installation Approach

The documentation set standardizes deployment into **repeatable, script-driven steps**:

1. **Raspberry Pi Installation**
   - Recommended path uses an `install.sh` script in `raspberry_pi/`:
     - Installs Python dependencies (`pyserial`) with appropriate flags.
     - Creates a persistent directory (`~/rplidar_streamer`).
     - Copies `rplidar_c1.py`, `pointcloud_streamer.py`, and related files.
     - Ensures serial permissions (`dialout` group, permissions on `/dev/ttyUSB0`).
     - Installs and enables `rplidar-streamer.service`.

2. **Companion Computer Installation**
   - Similarly scripted via `companion_computer/install.sh`:
     - Installs Python dependencies (`aiohttp`).
     - Creates `~/rplidar_forwarder`.
     - Copies `pointcloud_forwarder.py`, `forwarder.env`, service files.
     - Installs and enables `rplidar-forwarder.service`.
     - Uses the `forwarder.env` file as the single source of truth for TCP port, web server URL, and API key.

3. **Manual Installation**
   - Both Raspberry Pi and companion computer procedures include manual alternatives mirroring the scripted steps (creating directories, copying files, installing systemd units, enabling services) to aid debugging, customization, or environments where scripts are restricted.

4. **Service Management and Operations**
   - Daily operations rely on standard systemd commands:
     - `systemctl status/restart/stop rplidar-streamer`
     - `systemctl status/restart/stop rplidar-forwarder`
   - Real-time logs via `journalctl -u <service> -f` provide live visibility of system behavior, scan counts, and error conditions.

### 3. Configuration, Network Topology, and Environment Variables

A dedicated deployment configuration document defines an explicit **network topology** and associated environment variables:

- **Network Layout (Current Example)**
  - Raspberry Pi: `192.168.144.11`
  - Companion Computer: `192.168.144.15`
  - Web Server: development URL (HTTPS) with specific ingest endpoint.
  - TCP:
    - Raspberry Pi streams to companion computer on port `5555`.
  - HTTPS:
    - Companion computer posts to `/api/rest/pointcloud/ingest` on the web server.

- **Raspberry Pi Configuration**
  - `RPLIDAR_PORT=/dev/ttyUSB0`
  - `RPLIDAR_RPM=600`
  - `TCP_HOST=192.168.144.15`
  - `TCP_PORT=5555`
  - `SCAN_RATE_HZ=10`

- **Companion Computer Configuration (forwarder.env)**
  - `TCP_PORT=5555`
  - `WEB_SERVER_URL=<web_server_url>/api/rest/pointcloud/ingest`
  - `API_KEY=<configured_api_key>`

- **Web Server Configuration**
  - Expects API key in `X-API-Key` header to authenticate ingest requests.
  - Exposes WebSocket channels for browser clients.

- **Firewall and Connectivity**
  - Raspberry Pi: outbound TCP to companion (`5555`) must be allowed.
  - Companion: inbound TCP (`5555`) and outbound HTTPS (port 443).
  - Web server: inbound HTTPS (443) from the companion.

Configuration files (e.g., `forwarder.env`, systemd units) are provided with tested defaults, enabling operators to replicate the **working configuration** reliably across test setups.

### 4. Testing, Troubleshooting, and Validation

The methodology includes embedded validation and troubleshooting procedures:

1. **Network Reachability**
   - `ping` checks between Raspberry Pi and companion.
   - `nc -zv <companion_ip> 5555` from Raspberry Pi to validate TCP connectivity.
   - `curl` POST tests from the companion to the web server ingest endpoint, verifying API key and JSON format.

2. **Service and Log Verification**
   - Continuous `journalctl -u` tailing on both nodes to:
     - Confirm motor startup and scan acquisition on the Raspberry Pi.
     - Confirm scan forwarding and HTTP response codes on the companion.

3. **Expected Log Patterns**
   - Raspberry Pi:
     - Messages indicating connection to `/dev/ttyUSB0`, motor speed setting, scan start, TCP connection establishment, and periodic summaries such as:
       - “Streaming at 10 Hz…”
       - “Sent X scans, Y points total, Z points in last scan.”
   - Companion Computer:
     - “Listening on ('0.0.0.0', 5555)”
     - “Forwarding to <WEB_SERVER_URL>”
     - “Forwarded X scans (0 errors)”

4. **Common Issues and Remedies**
   - **Serial Port Permission Denied**: resolved by adding user to `dialout` and adjusting `/dev/ttyUSB0` permissions.
   - **Motor Not Spinning**: behavior clarified—motor only starts when `start_scan()` is called after setting motor speed and waiting for stabilization.
   - **Sparse Visualization**: mitigated by ensuring the streamer accumulates full 360° scans before transmitting.
   - **Low Data Rate**: diagnosis via network latency, CPU load, and HTTP response times, with wired connections recommended for reliability.

### 5. Alignment with Quiver SDK Vision

The implementation is intentionally structured to **mirror the companion-computer-mediated SDK architecture** described in the forum discussion:

- Uses **standardized data formats (JSON)** with clear fields (`timestamp`, `scan_id`, `points[]` with angle, distance, quality).
- Separates concerns cleanly:
  - Payload interface (sensor + Raspberry Pi).
  - Companion-level orchestration and networking.
  - Web/server level APIs and visualization.
- Provides a concrete testbed for:
  - Mission logic and intelligent behavior running on the companion computer.
  - Higher-bandwidth, high-rate telemetry (point clouds).
  - Integration with web-based dashboards and potential ground station plugins.

This methodology is intended to be **repeatable for other payload types**, serving as a template for future SDK modules.

---

## Results / Findings

### 1. Functional Outcomes

1. **Working End-to-End Terrain Mapping Pipeline**
   - The system achieves:
     - **Scan rate**: Target 10 Hz, typical 8–12 Hz.
     - **Points per scan**: 250–500, with a typical value around 350 points.
     - **End-to-end latency**: Approximately 100–150 ms from acquisition to browser display.
   - Real-time browser visualization provides a continuous 360° point cloud, demonstrating that the pipeline is capable of near-real-time terrain mapping suitable for aerial robotics use.

2. **Robust Deployment and Operations Model**
   - Scripted installations significantly reduce manual configuration steps and potential errors.
   - Systemd integration on both Raspberry Pi and companion computer ensures auto-start on boot, resilience to failures, and standardized log management.
   - The combination of quick-reference commands and detailed setup guidance supports both novice and advanced operators.

3. **Validated Networked Architecture**
   - TCP and HTTPS-based data transport across distinct nodes has been proven viable in a controlled test environment.
   - API-key-based authentication at the web server confirms that secure endpoints can be integrated without compromising ease of use.

### 2. Technical Insights and Constraints

1. **RPLidar C1 Behavior**
   - The motor and scanning control sequence is non-trivial:
     - `set_motor_speed()` alone is insufficient to start the motor.
     - A proper sequence (set speed → wait for stabilization → `start_scan()`) is required for reliable operation.
   - Accumulating complete 360° scans before transmission is key to high-quality visualization; sending partial scans leads to sparse and noisy displays.

2. **Bandwidth and Latency Characteristics**
   - The chosen combination of:
     - Length-prefixed TCP JSON messages.
     - Async HTTP POST forwarding.
     - WebSocket broadcasting.
   - Yields acceptable performance for high-frequency lidar payloads; however, it also highlights potential bottlenecks in:
     - Network quality (wired vs. wireless).
     - Web server throughput.
     - Browser rendering performance under higher-density point clouds.

3. **Configuration Sensitivity**
   - Static IP assignments, port alignment, and consistent environment variable usage are critical.
   - Small misconfigurations (e.g., incorrect IP, port mismatches, outdated API key) manifest as silent failures or intermittent data loss, underscoring the need for:
     - Clear configuration documentation.
     - Simple validation commands for each hop.

4. **Security and Environment Separation**
   - The use of a **development web server URL** and a specific API key indicates that the current system is in a **test/development** state.
   - Production deployment will require:
     - New, securely managed API keys.
     - Stable production domains.
     - Hardened firewall and TLS configurations.

### 3. Alignment with SDK Vision and Open Questions

1. **Evidence of Viability for Companion-Based SDK**
   - The RPLidar terrain mapping pipeline concretely demonstrates:
     - How a payload can be abstracted into a standalone module with clearly defined inputs and outputs.
     - How the companion computer can serve as an **intelligent integration layer**, aligning with the forum’s concept of running mission logic, perception, mapping, and OTA management on the companion.
   - This validates the **“companion-computer-mediated integration”** path as a practical and powerful foundation for an SDK.

2. **Emerging Ecosystem Elements**
   - The forum thread notes:
     - A test GitHub repository for the RPLidar test implementation.
     - A Quiver Hub web interface repository for the visualization front-end.
     - A Quiver Payload Architecture document as a broader architectural reference.
   - Together with the documentation set, these indicate a **growing ecosystem** of components around a unified payload/companion SDK concept.

3. **Unresolved Architectural Questions**
   - The forum explicitly raises several open questions that remain to be fully addressed:
     - Should the SDK remain purely MAVSDK-based, or evolve toward **ROS2** for broader robotics compatibility?
     - Should the companion computer be **standardized hardware** or an **open performance class** that supports multiple options?
     - Can the same framework extend beyond aerial platforms to ground robots, fixed installations, or hybrid systems under a common protocol and network stack?
   - These questions represent important design decisions for the long-term direction of the Quiver SDK.

---

## Next Steps / Recommendations

### 1. Productization and Hardening of the Current MVP

1. **Promote from Development to Staging/Production**
   - Migrate from the current development web server to a stable staging/production environment.
   - Rotate and securely manage API keys:
     - Separate keys for development, staging, and production.
     - Document key rotation procedures and storage best practices.
   - Review and tighten firewall rules, TLS configurations, and access control.

2. **Standardize Configuration Profiles**
   - Define configuration profiles for:
     - Local lab testing.
     - Field trials.
     - Production deployments.
   - Capture these profiles in version-controlled configuration files and environment templates to enable repeatable deployments.

3. **Operational Playbooks**
   - Codify day-to-day operations:
     - Start/stop/restart flows for all services.
     - Recovery procedures after network outages or node restarts.
     - Log inspection guidelines and common error patterns.

### 2. Generalization into a Quiver Payload/Companion SDK

1. **Extract Reusable SDK Components**
   - Identify and refactor:
     - Common data models (e.g., timestamped point clouds, telemetry messages).
     - Transport abstractions (TCP framing, HTTP/REST client, WebSocket integration).
     - Service management patterns (systemd units, environment-based configuration).
   - Package these into reusable libraries or templates for future payload implementations (lidar, cameras, rangefinders, flight telemetry).

2. **Define Stable APIs and Schemas**
   - Specify:
     - Canonical JSON schemas or equivalent message formats for sensor data, actuator commands, and mission events.
     - High-level APIs in Python/C++ for:
       - Telemetry.
       - Mission control.
       - Payload management.
   - Align these schemas and APIs with MAVLink/MAVSDK conventions where appropriate.

3. **Quiver Developer Manual and Reference Image**
   - Develop a **“Quiver Developer Manual”** that:
     - Introduces the SDK architecture.
     - Provides step-by-step guides for building, deploying, and debugging payload modules.
     - Includes example payloads (RPLidar terrain mapping, webcam streaming, rangefinder-based altitude visualizations, flight-attitude dashboard).
   - Build and distribute a **companion computer reference image** with:
     - Pre-installed SDK tools.
     - Standard telemetry routing.
     - Logging, OTA update, and diagnostic utilities.

### 3. Ecosystem and Interface Development

1. **Quiver Hub / Web Interface Evolution**
   - Integrate the lidar visualization into a broader **Quiver Hub** interface that:
     - Hosts multiple payload views (lidar, video, telemetry).
     - Provides mission status, logs, and configuration editing.
   - Define a standard mechanism for modular UI plugins corresponding to SDK payload modules.

2. **Ground Control Integration**
   - Extend existing GCS tools (e.g., Mission Planner, QGroundControl) with plugins that:
     - Discover and list registered Quiver payloads.
     - Expose basic configuration and control surfaces.
     - Link to or embed web-based visualizations.

3. **Developer Ecosystem and Registry**
   - Establish:
     - A public repository (or registry) of verified payload integrations following the SDK guidelines.
     - Contribution standards (code style, documentation, testing).
     - A lightweight certification process for payload modules intended for wider Quiver deployments.

### 4. Future Technical Investigations

1. **ROS2 vs. MAVSDK-Centric Architecture**
   - Perform a focused technical evaluation of:
     - Keeping the SDK purely MAVSDK-based.
     - Introducing ROS2 as a primary or optional compatibility layer.
   - Criteria should include:
     - Ecosystem maturity.
     - Performance characteristics for high-bandwidth payloads.
     - Integration complexity with existing Quiver avionics.

2. **Hardware Abstraction for Companion Computer**
   - Define minimum performance and connectivity requirements for companion computers (CPU, RAM, storage, network interfaces, radio support).
   - Decide whether to:
     - Certify a small set of recommended boards (e.g., RPi 4/5, specific x86 SBCs).
     - Or support a broader set of hardware via a clearly documented compatibility matrix.

3. **Scalability and Multi-Payload Coordination**
   - Extend the current single-lidar pipeline to multi-payload scenarios:
     - Simultaneous lidar + camera payloads.
     - Synchronized data streams for mapping and perception.
     - Coordinated control commands managed by the companion computer.

## References

- Arrow DAO forum topic: **“Exploring a Unified Payload and Companion Computer SDK for Quiver”** – conceptual framing of the Quiver SDK, architecture paths (direct-to-flight-controller and companion-computer-mediated), and example payload chains (including the RPLidar C1 mapping flow).  
  URL: https://dao.arrowair.com/t/exploring-a-unified-payload-and-companion-computer-sdk-for-quiver/138

- **DEPLOYMENT_CONFIG.md – Deployment Configuration**  
  Source for working IP addresses, ports, environment variables, data flow diagrams, performance targets, and troubleshooting notes for the RPLidar terrain mapping system.

- **QUICK_REFERENCE.md – RPLidar Terrain Mapping Quick Reference**  
  Source for condensed installation commands, configuration values, service management commands, testing procedures, expected logs, and performance metrics.

- **README.md – RPLidar C1 Terrain Mapping System Documentation Index**  
  High-level overview of the documentation set, roles of each document (SETUP_GUIDE, QUICK_REFERENCE, DEPLOYMENT_CONFIG, SYSTEM_SUMMARY), and navigation guidance for setup, configuration, and operations.

- **SETUP_GUIDE.md – RPLidar C1 Terrain Mapping System Setup Guide**  
  Complete installation and configuration instructions for Raspberry Pi and companion computer, detailed explanations of environment variables, protocol details (serial, TCP, HTTP), troubleshooting guidance, and library API references for the RPLidar C1 class.

- **SYSTEM_SUMMARY.md – RPLidar C1 Terrain Mapping System Summary**  
  Overview of system purpose, features, contents of the package, system requirements, key performance figures, known issues and solutions, and technical details on protocol and data pipeline implementation.

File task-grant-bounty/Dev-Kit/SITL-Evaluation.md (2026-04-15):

# SITL Obstacle Avoidance Evaluation

# Status

`Author: Zeynep`

`Status: Valid`

`Revision History: None`

`Replacement Log: None`

`Reference: None` 

# Project Description

This information note covers the Software-In-the-Loop (SITL) simulation environment established for safe and rapid exploration of obstacle avoidance (OA) parameters on Project Quiver. The SITL setup uses the standard ArduPilot SITL framework and is configured to resemble the physical and control characteristics of the Quiver airframe. The primary objective of this activity is behavioral exploration and parameter sensitivity analysis, not final performance validation.

# Methodology

## Simulation Environment Overview

The SITL environment is based on the same ArduPilot source code and branch currently used on Project Quiver flight hardware. The following aspects were aligned with the real vehicle:
- Airframe configuration (quadcopter)
- Approximate physical dimensions (arm length, propeller size)
- Mass and inertia estimates
- Control gains and parameter set identical to the current Quiver configuration
- Obstacle avoidance enabled using the same OA parameters as flight tests

This approach allows relative comparison of parameter effects while maintaining consistency with the flight-tested configuration.

## Sensor Simulation

### Top-Mounted LiDAR
The top-mounted 360° LiDAR used on Quiver is not directly available as a native SITL sensor model. To approximate its behavior:
- The SF45 LiDAR model was used in simulation.
- The model was configured to reflect the operational limitations of Quiver's top-mounted LiDAR (range and horizontal-only awareness).
- The simulated sensor feeds obstacle data into the ArduPilot proximity framework in the same manner as the real system.

This substitution provides a functional approximation suitable for studying avoidance logic and parameter interactions, while acknowledging that it does not replicate exact sensor physics or noise characteristics.

## Simulation Startup Configuration

The SITL environment is launched using the following command:

```bash
../Tools/autotest/sim_vehicle.py --map --console \
  -A "--serial5=sim:sf45b --serial6=sim:obstacle"
```

Key elements:
- `sim:sf45b` is used to simulate the top-mounted LiDAR input.
- `sim:obstacle` enables the obstacle simulation backend.
- The simulation is visualized and monitored using QGroundControl.

## Obstacle and Fence Interaction

Within the SITL environment, virtual obstacles and fences can be dynamically introduced. Obstacle geometry and placement can be modified, and vehicle response to parameter changes can be observed in real time.

This capability allows rapid iteration on obstacle margin behavior, BendyRuler lookahead effects, continuity and direction-change constraints, and general avoidance responsiveness.

## Scope and Limitations

While SITL provides a valuable and low-risk environment for experimentation, the following limitations apply:
- Sensor models are simplified and do not capture real-world noise, dropouts, or environmental effects.
- Aerodynamic effects (prop wash, wind interaction, inertia coupling) are approximated.
- Timing and latency characteristics differ from real hardware.
- Avoidance performance observed in SITL must not be considered flight-validated.

SITL results are therefore used to identify promising parameter ranges, eliminate clearly unsafe configurations, and inform flight test planning. Final validation of any obstacle avoidance behavior must be performed on real hardware under controlled flight test conditions.

# Results and Deliverables

At the time of writing:
- The SITL environment is operational.
- Obstacle avoidance behavior can be exercised and visualized.
- Parameter sensitivity studies are ongoing.
- Findings from SITL are being used to guide subsequent real-world flight testing.

QGroundControl screenshots showing the SITL obstacle avoidance simulation:

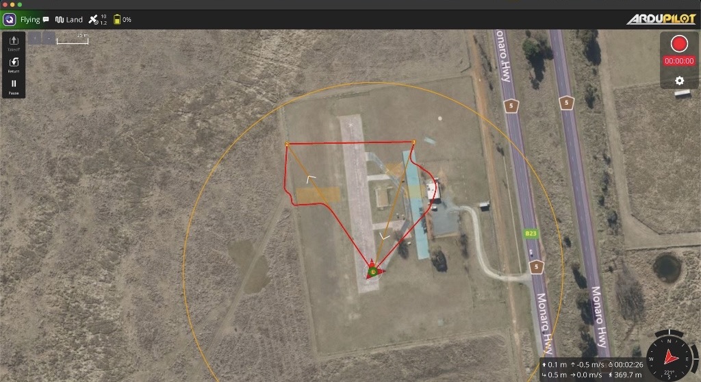
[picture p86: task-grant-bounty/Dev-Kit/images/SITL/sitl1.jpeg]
SITL QGroundControl View 1


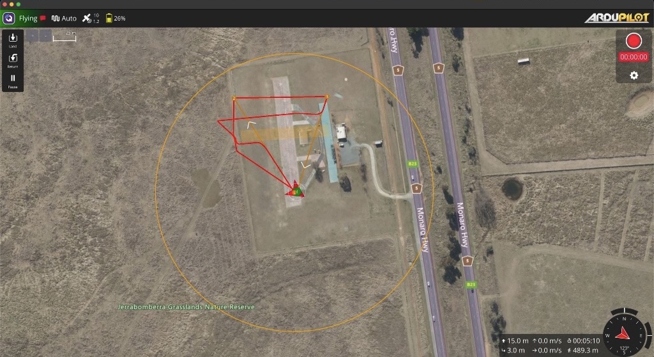
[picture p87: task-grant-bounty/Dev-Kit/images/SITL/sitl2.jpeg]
SITL QGroundControl View 2


The SITL setup provides a controlled and repeatable environment for early-stage obstacle avoidance tuning on Project Quiver. By closely matching firmware, parameters, and high-level vehicle characteristics, it enables safe exploration of avoidance behavior while clearly separating simulation insights from flight-validated performance.

# Remarks

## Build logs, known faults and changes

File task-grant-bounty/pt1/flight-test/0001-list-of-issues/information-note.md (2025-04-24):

# Status  

`Valid`

# Project Description

Project Quiver – Prototype 1 (PT1) flight logs between folders 1-6 underwent a comprehensive flight log review as part of its ongoing development and flight validation process. The goal of this phase was to evaluate PT1's performance under various flight conditions by manually reviewing all available flight test logs. This preliminary analysis is intended to identify potential issues for further investigation and to support the next stages of tuning and flight control refinement.

# Methodology

Each individual log file was manually sorted and thoroughly examined. Specific focus areas included:

- Flight modes and their transitions  
- Duration of each flight and executed maneuvers  
- Vibration levels during operation  
- GPS performance and satellite fix quality  
- EKF (Extended Kalman Filter) status, including any resets  
- Battery voltage consistency and ESC (Electronic Speed Controller) readings  
- General behavior of the flight controller  
- Trends in motor output signals  
- Additional general observations relevant to flight performance

Key findings and recurring patterns were documented throughout the review process. A summary table was prepared to consolidate the results, and it will also be shared in `.xlsx` format for future reference.

# Results and Deliverables

The review yielded several recurring issues requiring further investigation:

### 1. ESC0 Voltage Discrepancy

In all examined flights, the voltage reading from **ESC0** consistently appears approximately **0.5V lower** than that of the other ESCs and the main battery voltage. This may indicate a **sensor offset or measurement error**, and further investigation is required to confirm its cause and impact.

### 2. Motor Output Divergence

In some tests, particularly **while on the ground** and occasionally during **yaw inputs in flight**, motor outputs show **significant divergence** and in a small number of tests **hitting the motor limits**. These deviations may point to control imbalance or tuning inconsistencies.

### 3. Ground Resonance on Landing

Ground resonance phenomena were observed during **landings**, particularly during the **March 22, 2025** tests. This effect was **mostly seen in AUTO mode** and **to a lesser extent in POS mode**. These events should be reviewed in connection with landing gear dynamics and control system behavior near touchdown.

### 4. Oscillations and Tracking Deficiency in POS and AUTO Modes

Minor **oscillatory behavior** was noted in **Position Hold (POS)** and **AUTO** modes. Additionally, it was observed that **actual control parameters do not follow the target values as precisely as in STABILIZE mode**. A noticeable **altitude loss during the deceleration phase** suggests that both the **inner-most and outer-loop controllers** may require **further tuning**, which can be effectively performed using the existing flight test data. Although it appears to be better in the later tests, a suitable gain set should be utilized.

### 5. EKF Yaw Resets

**EKF yaw resets** were detected in **every test log**. While some yaw resets may occur under normal conditions, this recurring behavior warrants further analysis to ensure there is **no underlying issue being masked**, such as magnetic interference, poor GPS heading initialization, or insufficient yaw observability.

### 6. Yaw Reference Initialization Offset

In a small number of tests, the **initial yaw reference value** was found to be slightly offset from the **actual yaw angle**. Although observed infrequently, this inconsistency should be examined to ensure proper heading alignment during mission-critical operations.

A detailed summary table of all log file reviews can be found at the end of this document and is also available as an `.xlsx` file in the project folder.

# Remarks

The manual review of PT1’s flight logs has provided valuable insights into recurring issues and performance trends. While the overall system shows promising behavior, several areas require further analysis and tuning, particularly in relation to ESC readings, yaw stability, and controller performance in autonomous modes. The observations made during this phase will directly inform the upcoming test campaigns and system refinements.

 ---
 
 ## Summary Table of Log Reviews
 
 | Log Name     | Date                | Flight Summary                                                                       | Flight Modes   | Flight Duration     | Vibration Levels                    | GPS                  | EKF         | Power                               | Flight Performance                                                                     | Motor Outputs                                          | Error Messages   | Comments                                                                |
 |:-------------|:--------------------|:-------------------------------------------------------------------------------------|:---------------|:--------------------|:------------------------------------|:---------------------|:------------|:------------------------------------|:---------------------------------------------------------------------------------------|:-------------------------------------------------------|:-----------------|:------------------------------------------------------------------------|
 | 00000095.BIN | 2025-03-20 | On-Ground                                                                            | STAB           | 01:00 | OK                                  | OK                   | OK          | OK                                  | -                                                                                      | Random zeros?                                          | -                | -                                                                     |
 | 00000096.BIN | 2025-03-20 | Hover, stabilization                                                                 | STAB, ALT, POS | 01:35 | OK                                  | OK                   | 2 Yaw Reset | OK                                  | Good                                                                                   | Good, 2-4 giving more                                  | -                | Pitch and roll performance great                                        |
 | 00000097.BIN | 2025-03-20 | Hover, small inputs                                                                  | STAB, POS      | 03:20 | OK                                  | OK                   | 2 Yaw Reset | OK                                  | Good                                                                                   | Good, too much change during yaw inputs                | -                | Yaw input response should be studied                                    |
 | 00000098.BIN | 2025-03-20 | On-Ground                                                                            | STAB           | 00:15 | Higher but safe                     | OK                   | OK          | OK                                  | -                                                                                      | Hitting limits on ground                               | -                | ?                                                                       |
 | 00000099.BIN | 2025-03-20 | Horizontal Movements                                                                 | STAB, POS      | 03:00 | OK                                  | OK                   | 2 Yaw Reset | OK                                  | Good, POS needs tuning                                                                 | Good, too much change during yaw inputs                | -                | -                                                                     |
 | 00000100.BIN | 2025-03-21 | On-Ground                                                                            | STAB           | 00:30 | OK                                  | OK                   | OK          | OK                                  | -                                                                                      | Good                                                   | -                | -                                                                     |
 | 00000101.BIN | 2025-03-21 | On-Ground                                                                            | STAB           | 00:40 | OK                                  | OK                   | OK          | ESC0 slightly less                  | -                                                                                      | Good, 1-2 giving more                                  | -                | -                                                                     |
 | 00000102.BIN | 2025-03-21 | Takeoff, Landing                                                                     | STAB, POS      | 01:25 | OK                                  | OK                   | 2 Yaw Reset | ESC0 slightly less                  | Ground oscillations at the end                                                         | 1-2 giving way more on ground (around 28:30)           | -                | Check yaw at the beginning                                              |
 | 00000103.BIN | 2025-03-21 | On-Ground, No input                                                                  | GUIDED         | 02:00 | OK                                  | OK                   | OK          | Contactor Open                      | -                                                                                      | -                                                      | -                | Tried activating guided mode                                            |
 | 00000104.BIN | 2025-03-21 | On-Ground, No input                                                                  | POS            | 00:15 | OK                                  | OK                   | OK          | Contactor Open                      | -                                                                                      | -                                                      | -                | RC calibration?                                                         |
 | 00000105.BIN | 2025-03-22 | On-Ground, No input                                                                  | POS            | 00:15 | OK                                  | inside the workshop? | OK          | Contactor Open                      | -                                                                                      | -                                                      | -                | -                                                                     |
 | 00000106.BIN | 2025-03-22 | On-Ground                                                                            | STAB           | 01:00 | OK                                  | OK                   | OK          | ESC0 slightly less                  | Ground oscillations - no takeoff                                                       | Too much oscillation on ground                         | -                | -                                                                     |
 | 00000107.BIN | 2025-03-22 | Takeoff,  few maneuvers, Landing                                                     | STAB, POS      | 00:55 | OK                                  | OK                   | 2 Yaw Reset | ESC0 slightly less                  | A bit worse than others                                                                | 3-4 giving more                                        | -                | -                                                                     |
 | 00000108.BIN | 2025-03-22 | Takeoff, small maneuvers                                                             | ALT, POS       | 01:40 | OK                                  | OK                   | 2 Yaw Reset | ESC0 slightly less                  | A bit oscillatory                                                                      | Good                                                   | -                | Altitude changes in POS even though no throttle given                   |
 | 00000109.BIN | 2025-03-22 | Lateral and longitudinal movements, step inputs, yaw inputs                          | ALT, POS       | 03:10 | OK                                  | OK                   | 2 Yaw Reset | ESC0 slightly less                  | Good, check POS                                                                        | Good but check around 46:30                            | -                | -                                                                     |
 | 00000110.BIN | 2025-03-22 | On-Ground                                                                            | ALT, POS       | 00:30 | OK                                  | -                    | -           | No data                             | -                                                                                      | No data                                                | -                | It says armed but no battery data? Contractor probably open, armed how? |
 | 00000111.BIN | 2025-03-22 | Altitude changes in POS mode                                                         | ALT, POS       | 01:30 | OK                                  | OK                   | 1 Yaw Reset | ESC0 slightly less                  | A bit oscillatory                                                                      | Good but check around 09:36                            | -                | Route was like a big circle but very little pilot input. Check          |
 | 00000112.BIN | 2025-03-22 | Takeoff, very small maneuvers, altitude change, land                                 | ALT, POS       | 01:20 | Slightly higher at landing but safe | OK                   | 2 Yaw Reset | OK, too much oscillation at landing | A bit oscillatory                                                                      | Good                                                   | -                | Too much vibration at landing                                           |
 | 00000113.BIN | 2025-03-22 | Takeoff and landing in POS mode                                                      | POS            | 00:50 | OK                                  | OK                   | 2 Yaw Reset | ESC0 slightly less                  | Pitch twitches, roll better                                                            | Good                                                   | -                | -                                                                     |
 | 00000114.BIN | 2025-03-22 | Takeoff and landing in AUTO mode                                                     | POS, AUTO      | 00:50 | OK                                  | OK                   | 1 Yaw Reset | ESC0 slightly less                  | Worse than POS                                                                         | Good but twitches at landing                           | -              | -                                                                     |
 | 00000115.BIN | 2025-03-22 | Takeoff and land in POS mode, roll step                                              | POS            | 00:45 | OK                                  | OK                   | 1 Yaw Reset | ESC0 slightly less                  | Better but still needs tuning                                                          | Good                                                   | -              | -                                                                     |
 | 00000116.BIN | 2025-03-22 | Waypoint tracking with AUTO mode (line)                                              | POS, AUTO      | 01:15 | OK                                  | OK                   | 1 Yaw Reset | ESC0 slightly less                  | Better than 114, still needs checking                                                  | Good but twitches at landing                           | -              | -                                                                     |
 | 00000117.BIN | 2025-03-22 | Waypoint tracking with AUTO mode (triangle)                                          | POS, AUTO      | 01:30 | OK                                  | OK                   | 2 Yaw Reset | ESC0 slightly less                  | Similar to 116                                                                         | 1 giving less after some point, check attitudes        | -              | -                                                                     |
 | 00000118.BIN | 2025-03-22 | On-Ground, No input                                                                  | POS            | 00:20 | OK                                  | OK                   | -           | ESC0 slightly less                  | -                                                                                      | -                                                      | -              | -                                                                     |
 | 00000119.BIN | 2025-03-22 | On-Ground, No input                                                                  | POS            | 00:30 | OK                                  | OK                   | -           | ESC0 slightly less                  | -                                                                                      | -                                                      | -              | -                                                                     |
 | 00000120.BIN | 2025-03-22 | 10 m altitude test in AUTO mode                                                      | POS, AUTO      | 00:40 | OK                                  | OK                   | 1 Yaw Reset | ESC0 slightly less                  | Twitches                                                                               | 1-2 giving less but attitude is also positive          | -              | Possible wind, positive roll and pitch                                  |
 | 00000121.BIN | 2025-03-22 | 10 m altitude test in AUTO mode                                                      | POS, AUTO      | 00:30 | OK                                  | OK                   | 2 Yaw Reset | ESC0 slightly less                  | Worse than 120                                                                         | 1-2 giving less, small yaw divergence. Landing twitchy | -              | Possible wind, positive roll and pitch                                  |
 | 00000122.BIN | 2025-03-22 | 10 m altitude test in AUTO mode                                                      | POS, AUTO      | 00:30 | OK                                  | OK                   | 2 Yaw Reset | ESC0 slightly less                  | Needs tuning                                                                           | 1-2 giving less, small yaw divergence. Landing twitchy | -              | Possible wind, positive roll and pitch                                  |
 | 00000123.BIN | 2025-03-22 | 10 m altitude test in AUTO mode                                                      | POS, AUTO      | 00:25 | OK                                  | OK                   | 1 Yaw Reset | ESC0 slightly less                  | Worse in pitch and roll, faster in climb rate                                          | 1-2 giving less, small yaw divergence. Landing twitchy | -              | Possible wind, positive roll and pitch                                  |
 | 00000124.BIN | 2025-03-22 | 10 m altitude test in AUTO mode, stays longer at 10 m                                | POS, AUTO      | 00:35 | OK                                  | OK                   | 1 Yaw Reset | ESC0 slightly less                  | Similar to 123                                                                         | 1-2 giving less, small yaw divergence. Landing twitchy | -              | Possible wind, positive roll and pitch                                  |
 | 00000125.BIN | 2025-03-22 | 10 m altitude test in AUTO mode                                                      | POS, AUTO      | 00:30 | OK                                  | OK                   | 1 Yaw Reset | ESC0 slightly less                  | Less twitchy but not following too well                                                | 1-2 giving less, small yaw divergence. Landing twitchy | -              | -                                                                     |
 | 00000126.BIN | 2025-03-22 | 10 m altitude test in AUTO mode                                                      | POS, AUTO      | 00:30 | OK, a bit higher than others        | OK                   | 1 Yaw Reset | ESC0 slightly less                  | Still slow                                                                             | 1-2 giving less, small yaw divergence. Landing twitchy | -              | -                                                                     |
 | 00000127.BIN | 2025-03-22 | Takeoff and reach 10m in AUTO, descend and land in POS mode                          | POS, AUTO      | 01:00 | OK                                  | OK                   | 1 Yaw Reset | ESC0 slightly less                  | Overshoots in AUTO, POS slightly better than AUTO                                      | Good, landing less twitchy                             | -              | -                                                                     |
 | 00000128.BIN | 2025-03-22 | 10 m altitude test in AUTO mode                                                      | POS, AUTO      | 00:30 | OK                                  | OK                   | 1 Yaw Reset | ESC0 slightly less                  | Oscillatory behavior                                                                   | Landing twitchy                                        | -              | -                                                                     |
 | 00000129.BIN | 2025-03-22 | Waypoint tracking with AUTO mode (square). In the last leg, POS activated for return | POS, AUTO      | 01:00 | OK                                  | OK                   | 1 Yaw Reset | ESC0 slightly less                  | Angle tracking is the best in all AUTO flights. POS is also better.                    | Good, landing is great                                 | -              | Best test, check gains                                                  |
 | 00000130.BIN | 2025-03-22 | Waypoint tracking with AUTO mode (zigzag with elevation change)                      | AUTO           | 02:00 | OK                                  | OK                   | 1 Yaw Reset | ESC0 slightly less                  | Angle tracking is good, less altitude drop during deceleration. Landing is a bit fast. | Hit the limits yaw turns. Investigate.                 | -              | -                                                                     |

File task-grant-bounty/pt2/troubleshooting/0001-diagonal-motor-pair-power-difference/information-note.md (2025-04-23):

# Status

`Valid`

# Project Description

This information note describes the solution to the problem that the two diagonal motor pairs (in a quadcopter) have a significant difference in performance during operation.

# Methodology

A difference in performance between the diagonal motor pairs, as shown in the following illustration, can be eliminated by realigning the motors. The difference in performance may also be caused by other problems (e.g. defective propellers), but this information note only refers to the realignment.

Picture 1: Power level before realignment

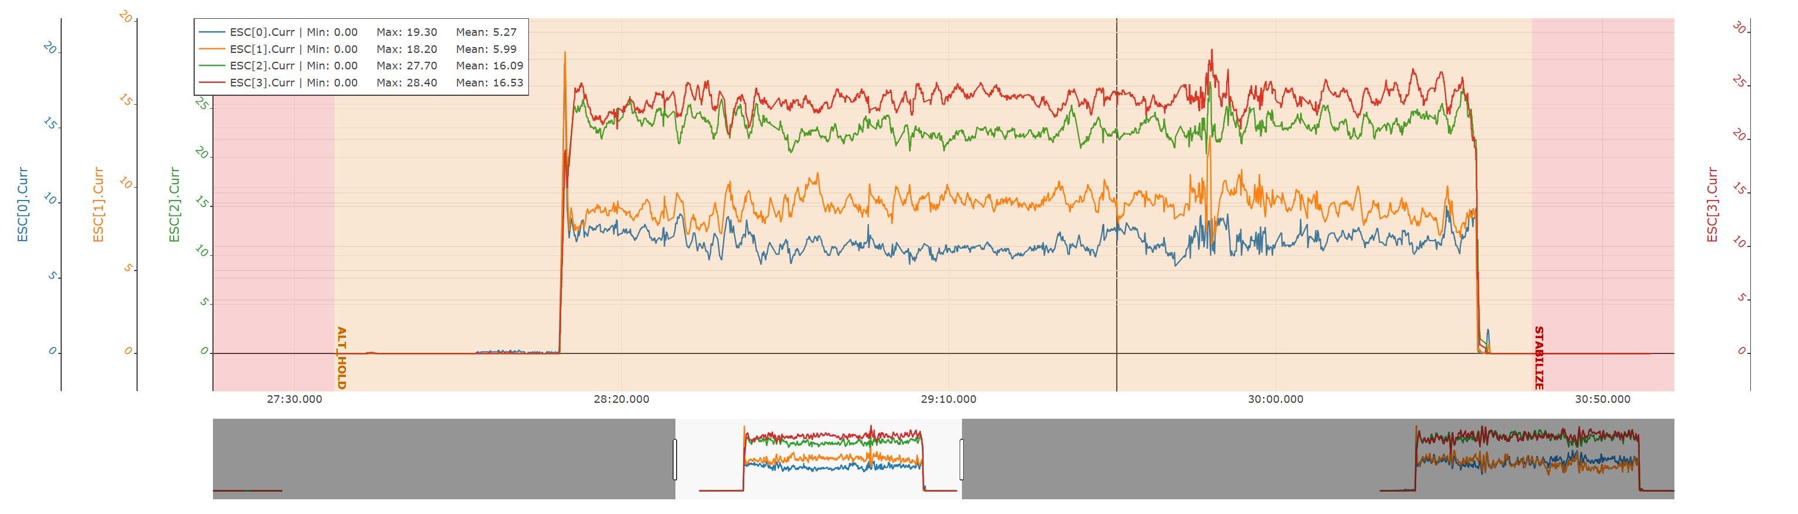
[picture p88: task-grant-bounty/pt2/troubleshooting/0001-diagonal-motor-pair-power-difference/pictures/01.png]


When motors on a drone are not mounted perfectly horizontally, their thrust is slightly angled, creating unintended torque and directional forces. Since drones rely on pairs of clockwise (CW) and counterclockwise (CCW) spinning motors to balance torque, any misalignment disrupts this balance. The flight controller compensates by adjusting thrust, often increasing power to one diagonal motor pair (either CW or CCW) to counter the imbalance. This causes that motor pair to draw more current than the other, leading to uneven power usage and possible long-term wear or performance issues.

### Steps to Fix the Imbalance:

#### 1. Identify the Issue:

Review flight logs to confirm a consistent power difference between diagonal motor pairs.

#### 2. Check Motor Alignment:

Place your flat tool across each motor pair:

- Front-Left ↔ Front-Right (FL-FR)
- Front-Right ↔ Back-Right (FR-BR)
- Back-Right ↔ Back-Left (BR-BL)
- Back-Left ↔ Front-Left (BL-FL)

Look closely for any visible gaps or angles between the motor surfaces and the tool. A tilt will be visible as a small gap or misalignment.

#### 3. Adjust Misaligned Motors:

Loosen the 4 screws on the misaligned motor’s mount (do not remove them).

Reposition the motor until it sits level. Use the tool to confirm there are no visible gaps.

#### 4. Secure the Motor:

Once level, carefully tighten the screws while maintaining alignment.

Recheck with your tool to ensure the motor hasn’t shifted during tightening.

#### 5. Final Check:

Repeat the leveling check across all four motor-to-motor positions to ensure full alignment.

#### 6. Test Flight:

Conduct a controlled test flight and review logs to confirm the power draw is now balanced.

# Results and Deliverables

#### 1. Identify the Issue:

- The performance level of two motors is much higher than that of the other two (see picture 1 in this information note)

#### 2. Check Motor Alignment:

- The alignment check was performed with a large spirit level:

  Picture 2: Alignment check

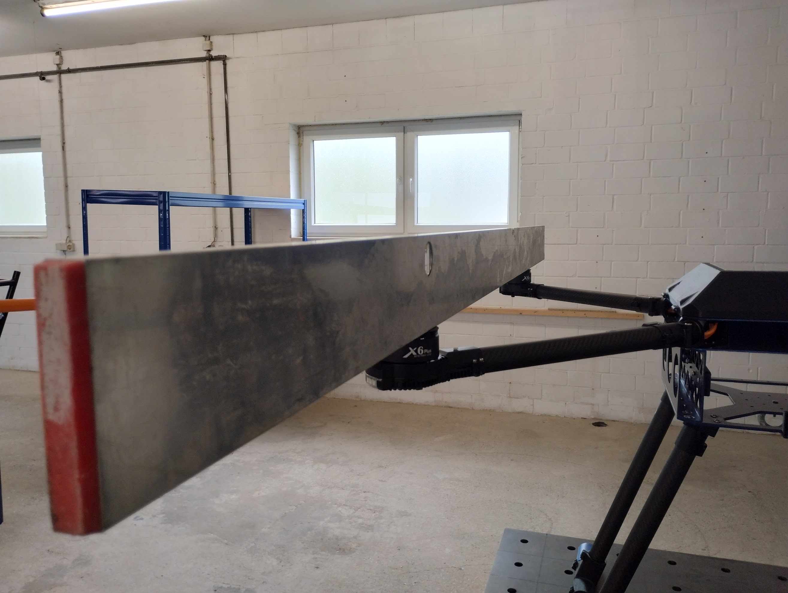
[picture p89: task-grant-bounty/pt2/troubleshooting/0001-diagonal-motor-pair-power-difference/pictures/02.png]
  

  Some misalignments were visible:

  Picture 3: Small gap

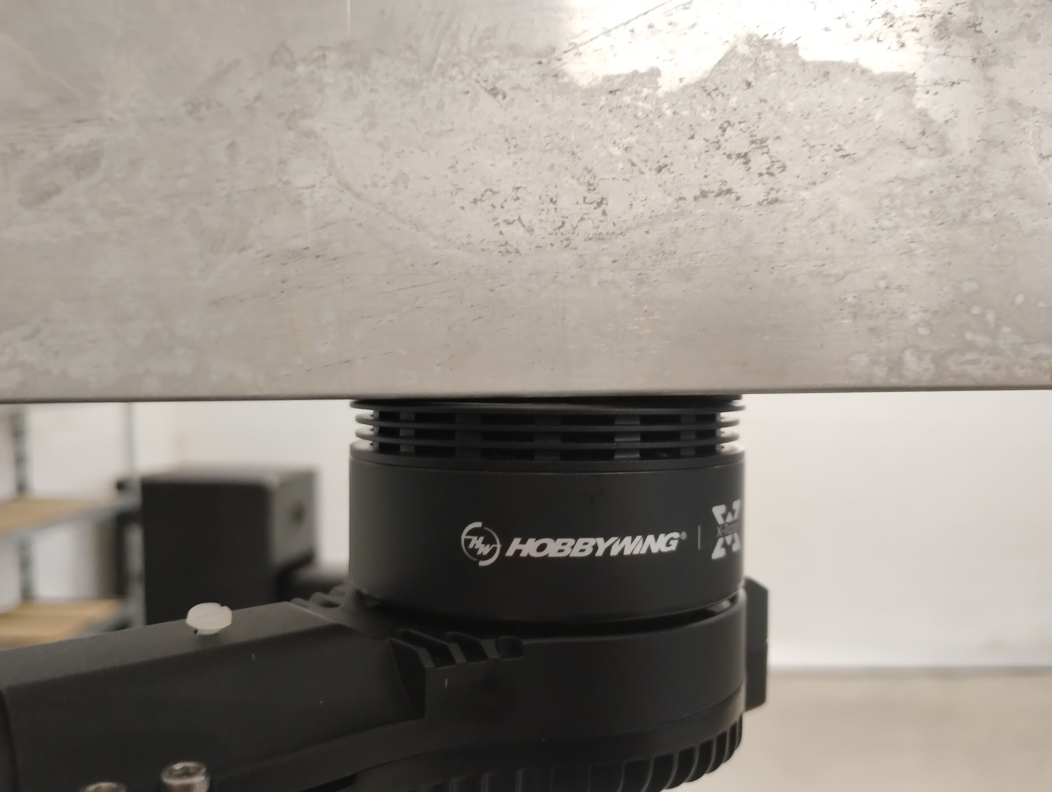
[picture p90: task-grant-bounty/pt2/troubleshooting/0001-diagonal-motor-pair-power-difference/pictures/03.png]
  

  #### 3. Adjust Misaligned Motors:
  - The motor tilt was adjusted by hand. During alignment the spirit level was kept on the motors. All four motors were realigned

  #### 4. Secure the Motor:
  - All motor mount screws were carefully tightened

  #### 5. Final Check:
  - A final check was performed between all motor pairs. No gaps are visible

  #### 6. Test Flight:
  - The logs show a much better power distribution between the motors. The alignment was successful

  Picture 4: Power level after realignment

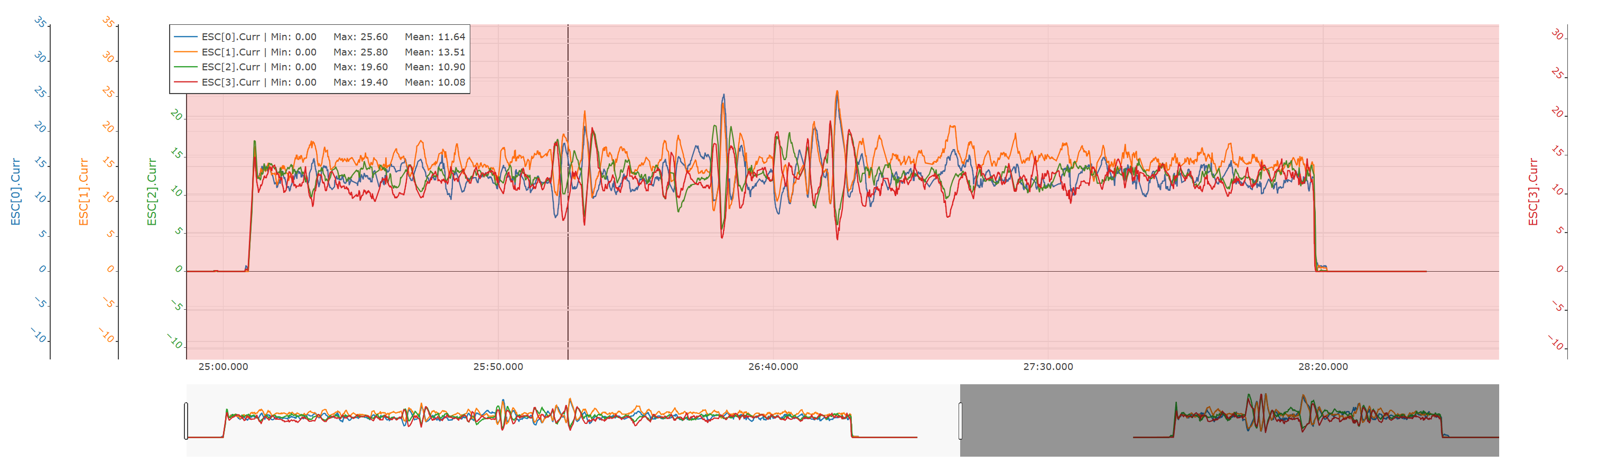
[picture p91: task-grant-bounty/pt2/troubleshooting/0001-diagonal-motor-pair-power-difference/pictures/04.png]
  

## Files

The photos can be found in a separate github folder.

# Remarks

- In this case I was performing the realignment two times, because i over-corrected it the first time

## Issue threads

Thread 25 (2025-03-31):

Update PT1 Battery Enclosure

thomasgarrison, 2025-03-31:
Update the enclosure so that the battery is 6mm further back, and add provisions for a dust lid for the pixhawk

Closed 2025-05-07.

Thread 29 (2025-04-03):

04/07 - Flight Test Setup

alperenag, 2025-04-03:
- Creating a flight test setup similar to one we have in Texas

- "arrow-ge" discord account

- Order 1 more battery

Julius-eng, 2025-04-07:
- Battery is ordered
- I also ordered a charger

Julius-eng, 2025-04-08:
To get to the test site, I have to walk about 50-100m across terrain. To create a setup similar to the one in texas, I decided on the following:
- Ordered a handcart with large wheels. I will build a second level on top so that it is easy to work on. There is space on the lower level to transport the drone at the same time.
- Ordered a monitor with gas spring mount
- Ordered a mini pc
- Ordered a holder for a dslr camera that can be adjusted quickly
- I still have a DSLR camera, which is not used often and can be used permanently for the setup

It will take a few days until all the things arrive and the table setup is ready. I'll try to have everything ready for Monday 14.04.

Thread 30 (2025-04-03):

04/21 - Flight Test Log Analyzer

alperenag, 2025-04-03:

alexdada555, 2025-04-10:
#Update

System developed in python as a web application extracting and producing plots of the following parameters

## Estimation Status (EKF3/Normalised Innovations EK3 Lane1)

- XKF4[0].SV
- XKF4[0].SP
- XKF4[0].SH
- XKF4[0].SM
- XKF4[0].SVT

## GPS Status (Sensors/GPS/GPS Accuracy)

- GPA[0].HAcc
- GPA[0].SAcc
- GPA[0].VAcc

## Vibration Metrics (Sensors/Accelerometer/Vibration)

- VIBE[0].VibeX
- VIBE[0].VibeY
- VIBE[0].VibeZ

## Clipping( Sensors/Accelerometer/Clipping)

- VIBE[0].Clip
- VIBE[1].Clip

## Rate Controller Performance

- RATE.R and RATE.RDes
- RATE.P and RATE.PDes
- RATE.Y and RATE.YDes

## Attitude Controller Performance

- ATT.Roll and ATT.DesRoll
- ATT.Pitch and ATT.DesPitch
- ATT.Yaw and ATT.DesYaw

## PWM Outputs

- RCOU.C1
- RCOU.C2
- RCOU.C3
- RCOU.C4

## RC Inputs

- RCIN.C1
- RCIN.C2
- RCIN.C3
- RCIN.C4

## Battery related parameters

- BAT[0].Volt
- BAT[0].Curr
- BAT[0].Temp

---
We can add more later but these should be sufficient for now.

These are being produced as individual graph images and displayed on a web page
Core functionality is ready

# Currently

Exploring how best to deploy it to a remote server for accessibility and scalability to multi  user data capture and storage

More functionality can be added in late

alexdada555, 2025-04-15:
# Update

Test Implementation Repository Created and functional  Local deployment produced

[Flight Log Analyser Repository](https://github.com/alexdada555/Flight-Log-Analyser)

alexdada555, 2025-04-29:
Application Updates in coming with `.Log` Files parsing functionality using this library https://pypi.org/project/pymavlog/

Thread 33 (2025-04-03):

04/08 - PT1.5 Harnessing Modifications

alperenag, 2025-04-03:
- Routing the cables for the battery, FC and the motors for the new PCB on PT1.5

errrks, 2025-04-08:
[Wiring table](https://docs.google.com/spreadsheets/d/16EMP2wPfAB1RD0uh3B_RAArtTbWv5ikxNuRASy50kpA/edit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) in CSV format. Will need to have a completed model of the drone before I can do routing.

errrks, 2025-05-01:
Information note PR opened: https://github.com/Arrow-air/project-quiver/pull/67

Closed 2025-05-01.

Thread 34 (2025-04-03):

04/08 - PT1.5 Battery Enclosure & Landing Gear Design

alperenag, 2025-04-03:
- PT1.5 Battery Enclosure & Landing Gear Design

errrks, 2025-04-10:
Where can we see the completed CAD design?

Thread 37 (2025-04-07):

04/11 - Accomplish large EU operator license for drones

Julius-eng, 2025-04-07:
- Receive license to operate drones up to 25kg in the EU
- Insure the Quiver PT2 prototype

Julius-eng, 2025-04-09:
- First part of the license is completed

Julius-eng, 2025-04-10:
- License is completed
- Insurance is pending

alperenag, 2025-04-11:
Congrats!

Closed 2025-04-11.

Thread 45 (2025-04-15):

04/15 - PT2 Realignment of the motor positions

Julius-eng, 2025-04-15:
Issue of motor power contrast

Julius-eng, 2025-04-16:
Realignment solved the issue.
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

Closed 2025-04-16.

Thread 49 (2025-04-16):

04/18 - Create information note for correcting the motor orientation

Julius-eng, 2025-04-16:
Create information note for correcting the motor orientation. Motor orientation needs to be corrected in case a continuous thrust imbalance is occurring during flight (diagonally pairs have different power level).

Julius-eng, 2025-04-22:
https://github.com/Julius-eng/project-quiver-05032025/blob/main/task-grant-bounty/pt2/troubleshooting/0001-diagonal-motor-pair-power-difference/information-note.md

Closed 2025-04-22.

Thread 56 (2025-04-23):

04/24 - Small repair on PT2

Julius-eng, 2025-04-23:
During the last flight, a screw became loose, causing the connection to heat up. There are two main causes for this:
1. an iron washer led to moderate heat generation
2. the clamping of the screw connection involved the 3D printing. The heat has reduced the contact pressure as the plastic has softened due to the heat. The lack of contact pressure exacerbated the heating.

The landing was completed on time.

Julius-eng, 2025-04-24:
- New fuse installed
- Screw connection upgraded with copper washers
- No more plastic in between the screw connection
- Locking nuts used and additional loctite
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

Closed 2025-04-24.

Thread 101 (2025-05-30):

06/13 - Testing of V1 of battery connector PCB (BC_PCB)

Julius-eng, 2025-05-30:

Julius-eng, 2025-06-20:
Initial test phase completed:
- Two small issues resolved
- All functions working
- Precharge circuit: No significant heat development
- In flight: PCB temperature rise stops at 46°C (at ambient temperature of 26°C and no payload attached)
- A flight of over 20 minutes was successfully completed

Closed 2025-06-20.

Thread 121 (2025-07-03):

07/17 - Preliminary Investigation of Ranch Compass Calibration Problem

alperenag, 2025-07-03:

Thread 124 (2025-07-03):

07/15 - Build the Second Set of PCBs & Test Ethernet

alperenag, 2025-07-03:

Julius-eng, 2025-07-16:
- Second set build is completed
- Ethernet test turned out that the giga nano 4 port ethernet switch is not usable on the current design of the PCBs, because a layout fault on the main PCB. Will adjust for next version.

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

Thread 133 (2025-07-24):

07/31 - PT3 investigate voltage drop issue

Julius-eng, 2025-07-24:

Closed 2025-07-29.

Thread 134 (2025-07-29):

08/04 - Write information note for startup problem and precharge resistor change

Julius-eng, 2025-07-29:

Julius-eng, 2025-08-04:
https://github.com/Arrow-air/project-quiver/pull/140

Closed 2025-08-04.

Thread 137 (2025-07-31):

08/06 - Enclosure Modification

alperenag, 2025-07-31:
The current enclosure has problems as indicated in Problem Sheet

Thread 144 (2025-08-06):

08/08 - Camera Mount Modification

alperenag, 2025-08-06:
Move the camera from the rear to the front, modify the altitude sensor mount to house the camera

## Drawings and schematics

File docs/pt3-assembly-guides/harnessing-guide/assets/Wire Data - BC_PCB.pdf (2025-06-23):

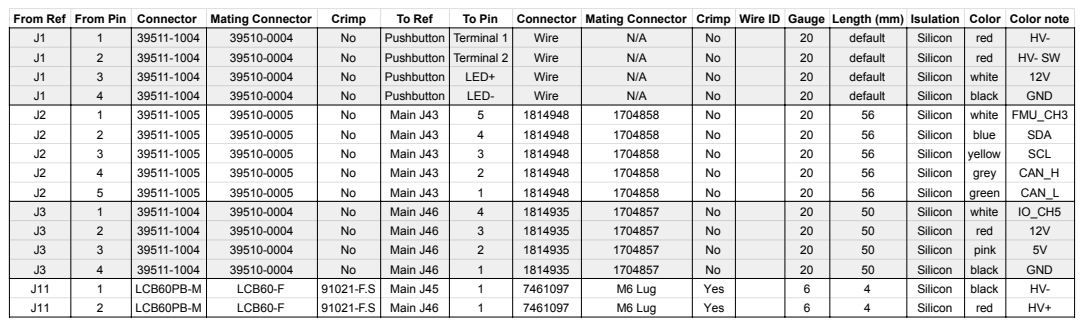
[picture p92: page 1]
From Ref From Pin Connector; Mating Connector; Crimp; To Ref; To Pin; Connector Mating Connector Crimp Wire ID Gauge Length (mm) Isulation Color Color note

J1 J1 | 1 2 3 4 | 39511-1004 39511-1004 | 39510-0004 39510-0004 | No No | Pushbutton Pushbutton | Terminal 1 Terminal 2 LED+ LED- | Wire Wire | N/A N/A | No No | 20 20 | default default | Silicon Silicon | red red white black | HV-HV- SW 12V GND

J2 J2 J2 J2 J2 | 1 2 3 4 5 | 39511-1005 39511-1005 39511-1005 39511-1005 39511-1005 | 39510-0005 39510-0005 39510-0005 39510-0005 39510-0005 | No No No No No | Main J43 Main J43 Main J43 Main J43 Main J43 | 5 4 3 2 1 | 1814948 1814948 1814948 1814948 1814948 | 1704858 1704858 1704858 1704858 1704858 | No No No No No | 20 20 20 20 20 | 56 56 56 56 56 | Silicon Silicon Silicon Silicon Silicon | white blue yellow grey green | FMU_CH3 SDA SCL CAN_H CAN_L

J3 J3 | 1 2 3 4 | 39511-1004 39511-1004 | 39510-0004 39510-0004 | No No | Main J46 Main J46 | 4 3 2 1 | 1814935 1814935 | 1704857 1704857 | No No | 20 20 | 50 50 | Silicon Silicon | white red pink black | IO_CH5 12V 5V GND

J11 | 1 2 | LCB60PB-M | LCB60-F | 91021-F.S | Main J45 Main J46 | 1 1 | 7461097 | M6 Lug | Yes | 6 6 | 4 4 | Silicon | black red | HV-HV+

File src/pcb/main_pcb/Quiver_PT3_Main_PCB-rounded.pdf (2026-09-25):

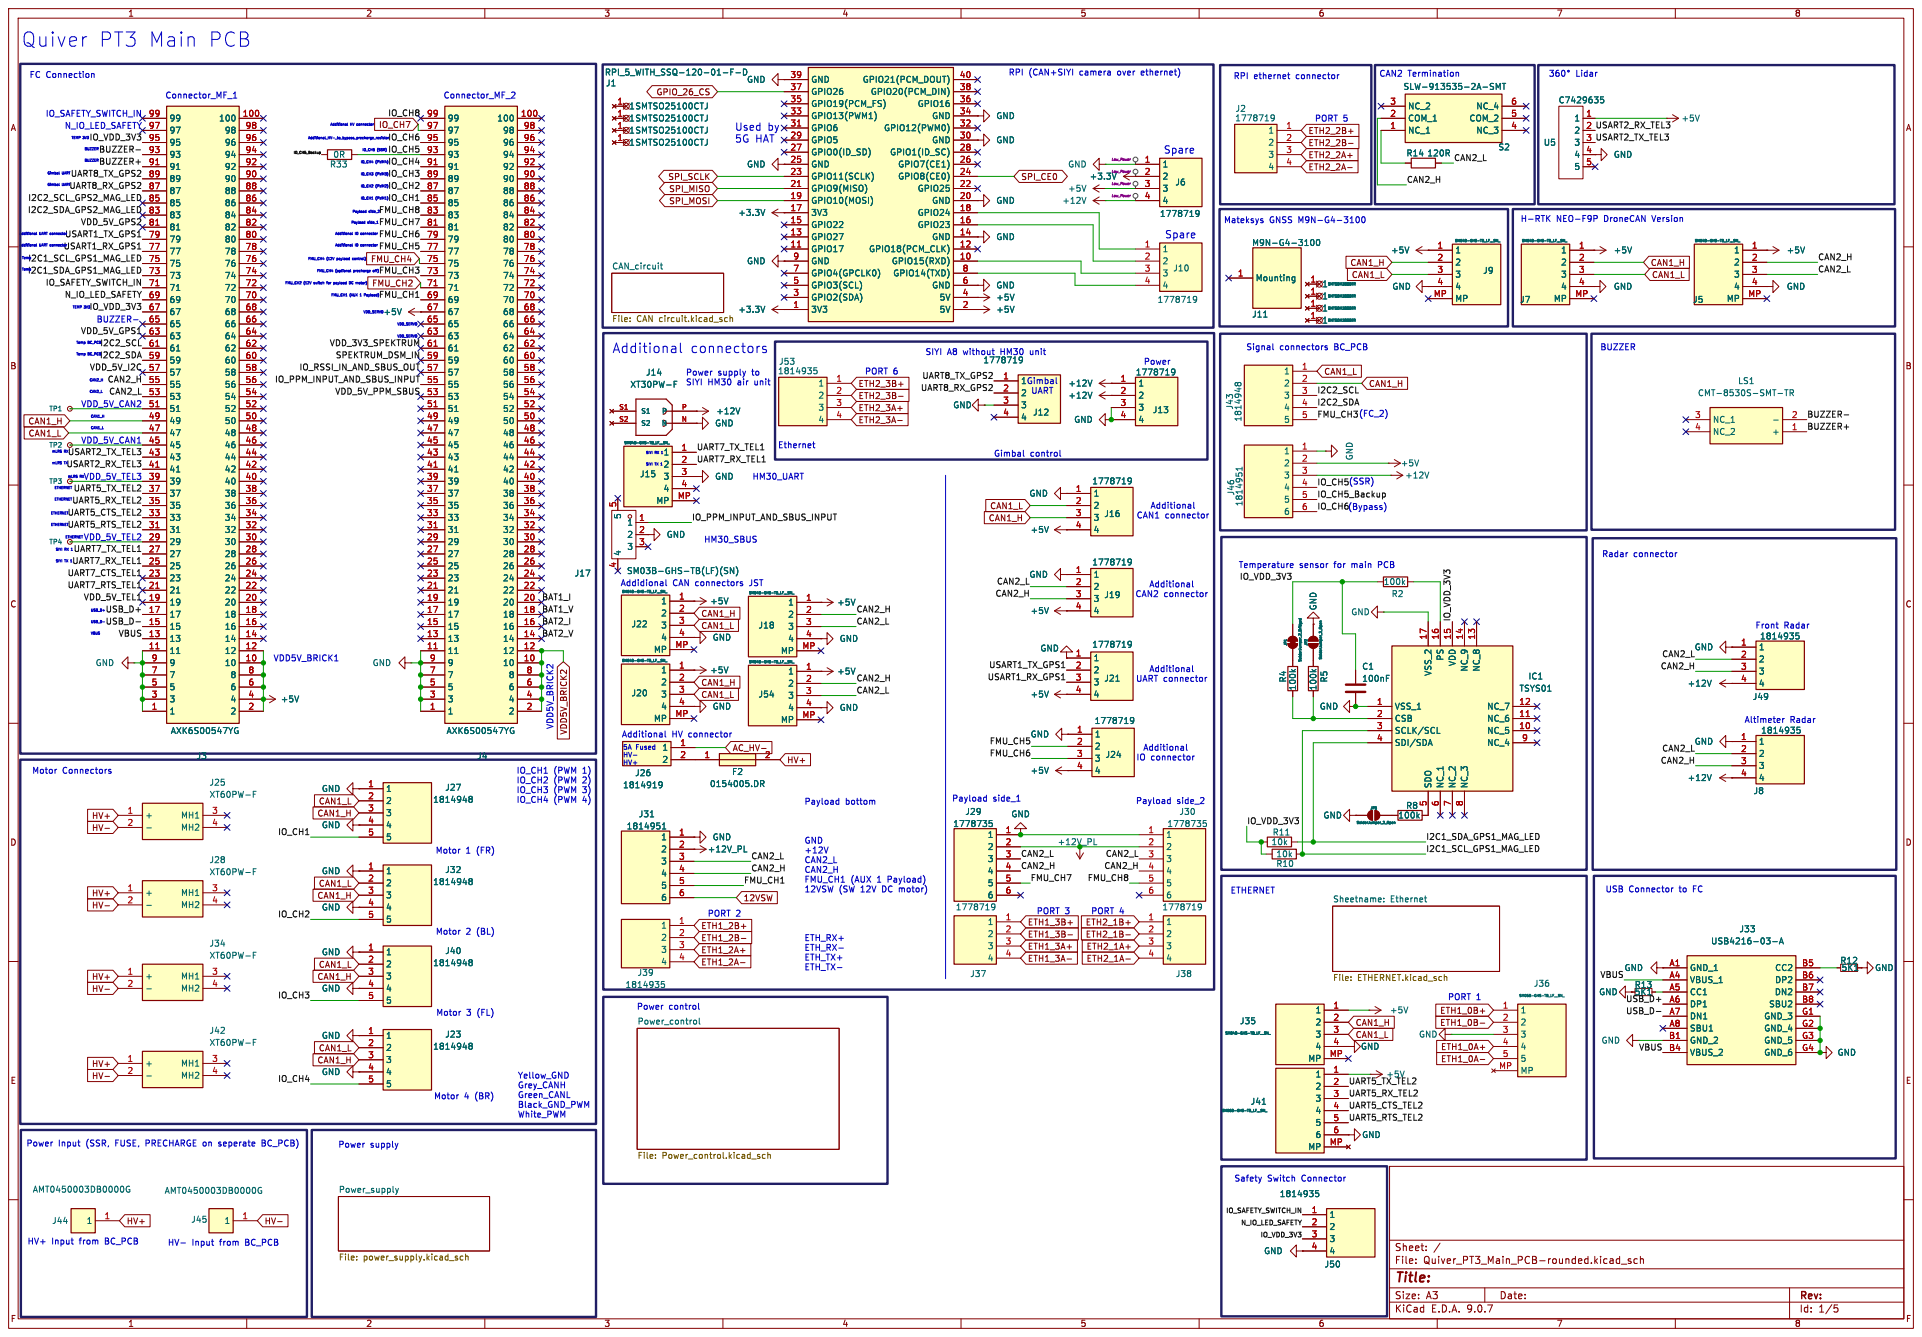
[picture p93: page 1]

RPI (CAN+SIYI camera over ethernet) Connector_MF_2

Power supply to SIYI HM30 air unit
+12V GND

SIYI RX 1 SIYI TX 1

Additional UART connector HV+ Input from BC_PCB

Power Input (SSR, FUSE, PRECHARGE on seperate BC_PCB)

Id: 1/5 Title: File: Quiver_PT3_Main_PCB-rounded.kicad_sch Sheet: /

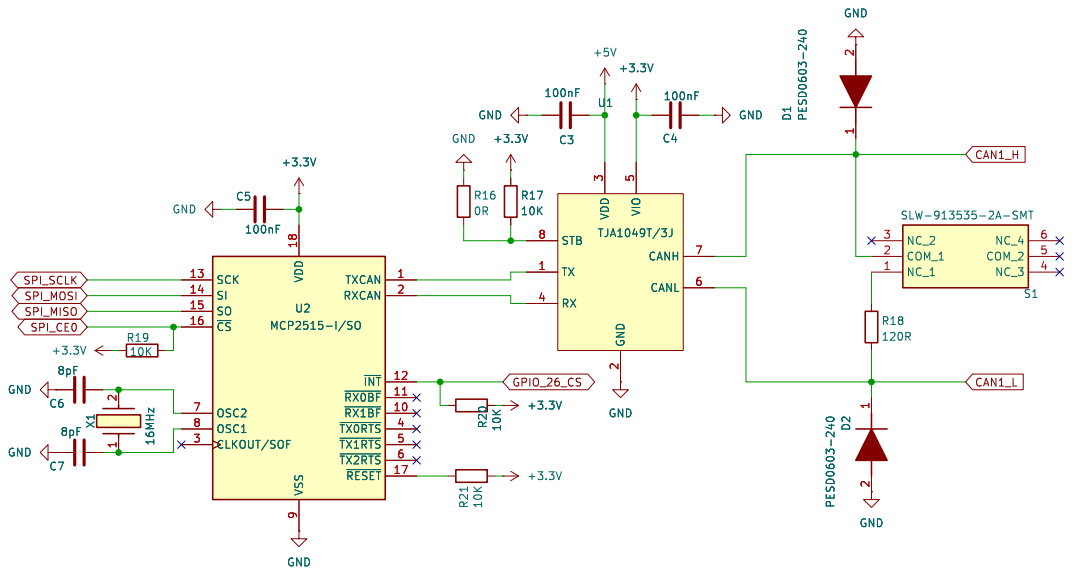
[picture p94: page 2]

9 TXCAN 1 RXCAN 2 ~{INT~{}} 12 ~{RX0BF~{}} 11 ~{RX1BF~{}} 10 ~{TX0RTS~{}} 4 ~{TX1RTS~{}} 5 ~{TX2RTS~{}} 6 ~{RESET~{}} 17 +3.3V C5

9 TXCAN 1 RXCAN 2 ~{INT~{}} 12 ~{RX0BF~{}} 11 ~{RX1BF~{}} 10 ~{TX0RTS~{}} 4 ~{TX1RTS~{}} 5 ~{TX2RTS~{}} 6 ~{RESET~{}} 17 U2 MCP2515-I/SO

Id: 2/5 Title: File: CAN circuit.kicad_sch Sheet: /CAN_circuit/ GND

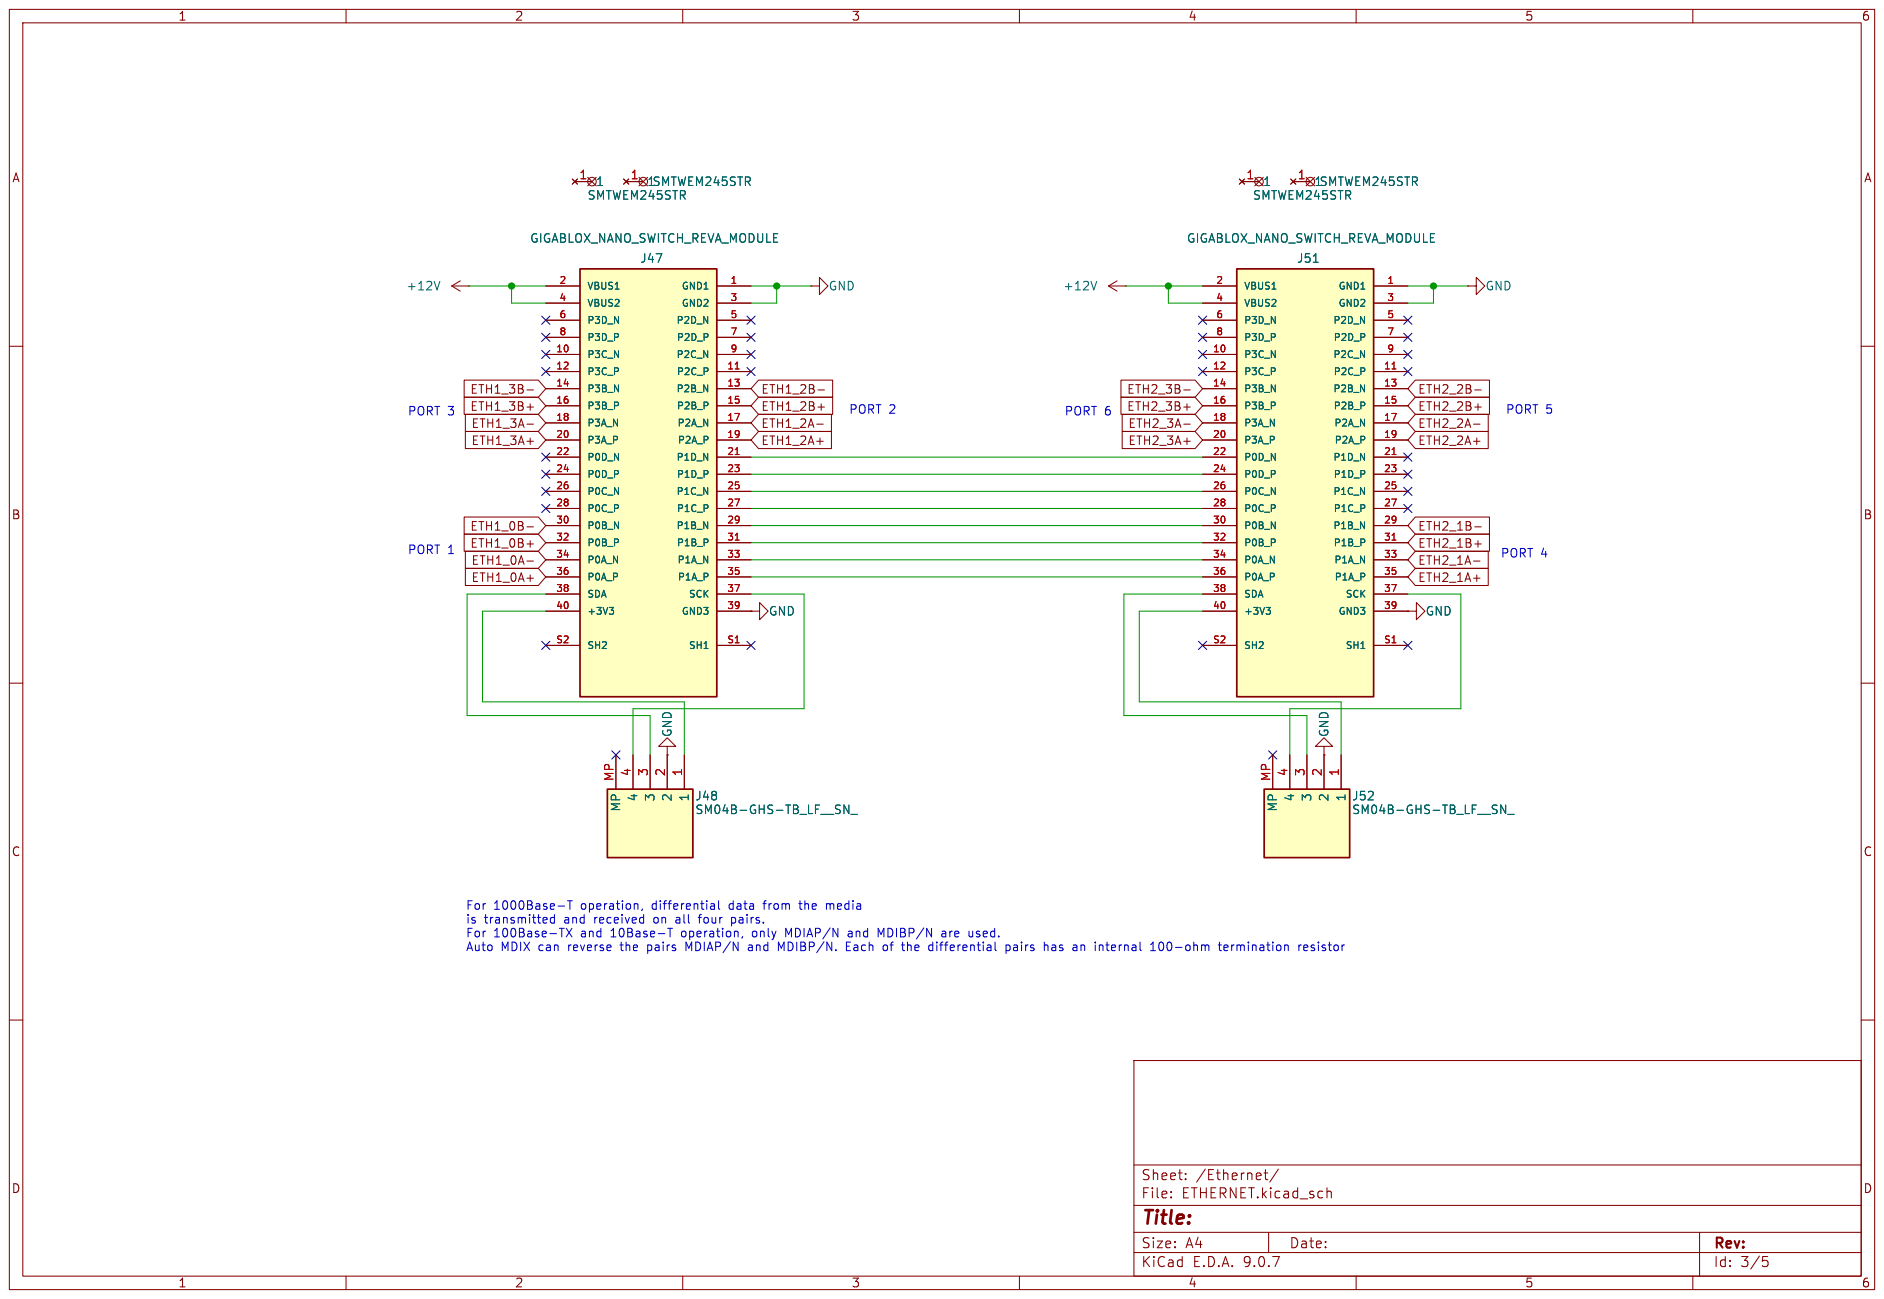
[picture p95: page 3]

J52 SM04B-GHS-TB_LF__SN_ GND GND GND

4 MP MP GND GND

Id: 3/5 Title: File: ETHERNET.kicad_sch Sheet: /Ethernet/

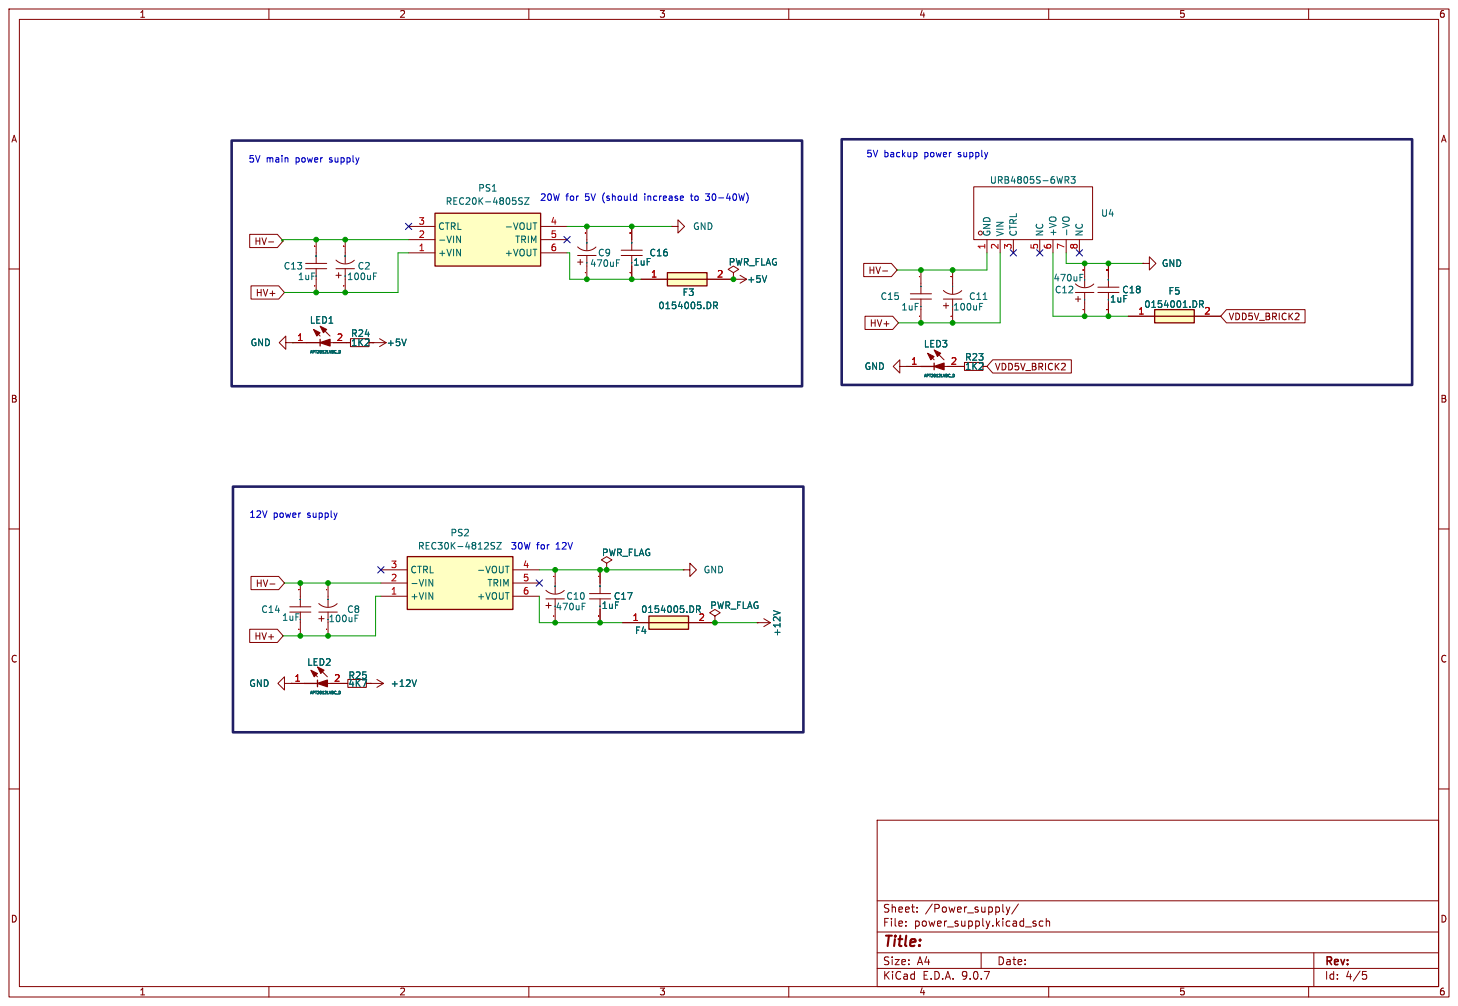
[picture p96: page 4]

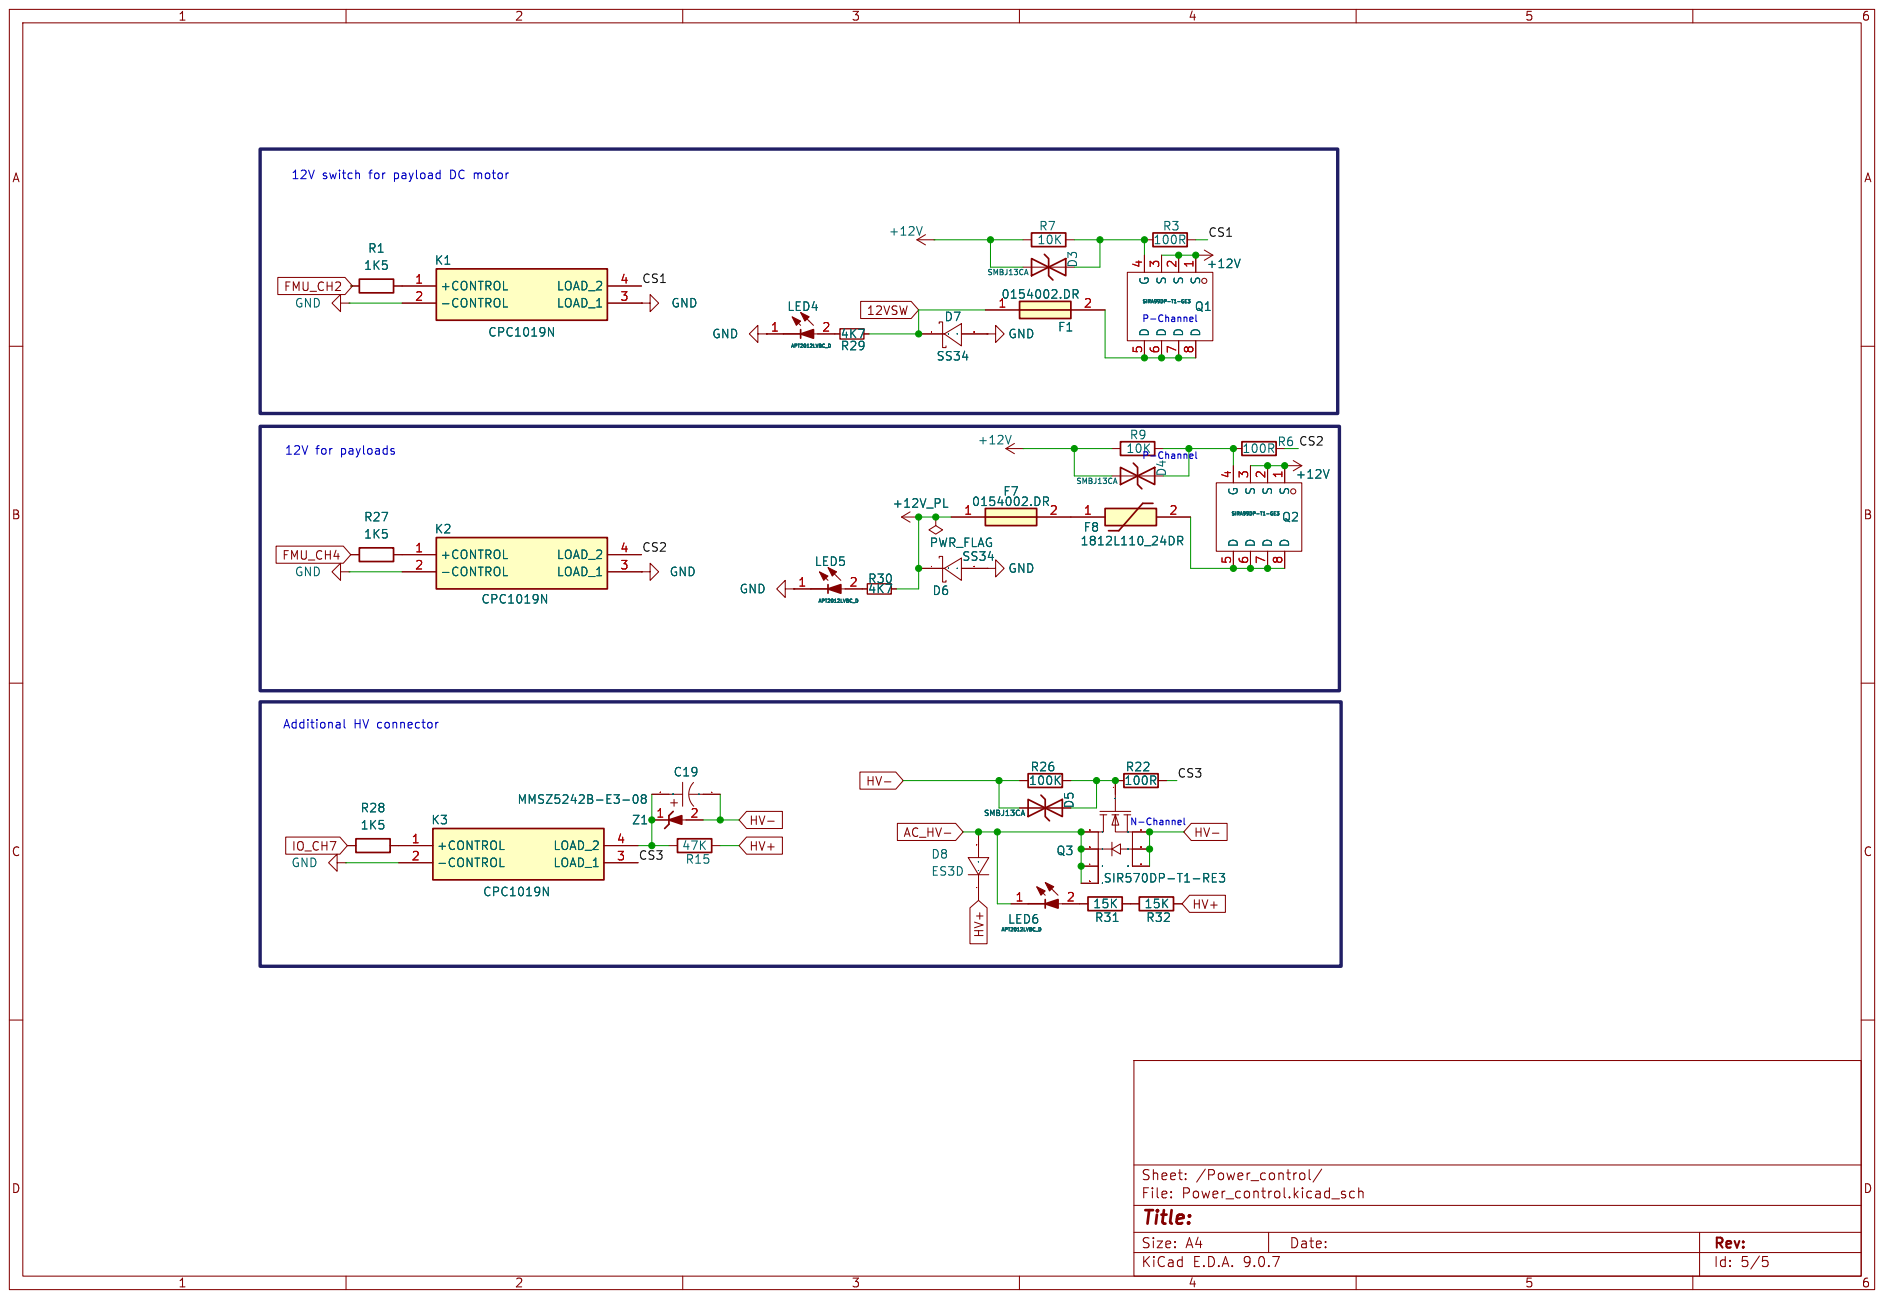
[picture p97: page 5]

Id: 5/5 Title: File: Power_control.kicad_sch Sheet: /Power_control/

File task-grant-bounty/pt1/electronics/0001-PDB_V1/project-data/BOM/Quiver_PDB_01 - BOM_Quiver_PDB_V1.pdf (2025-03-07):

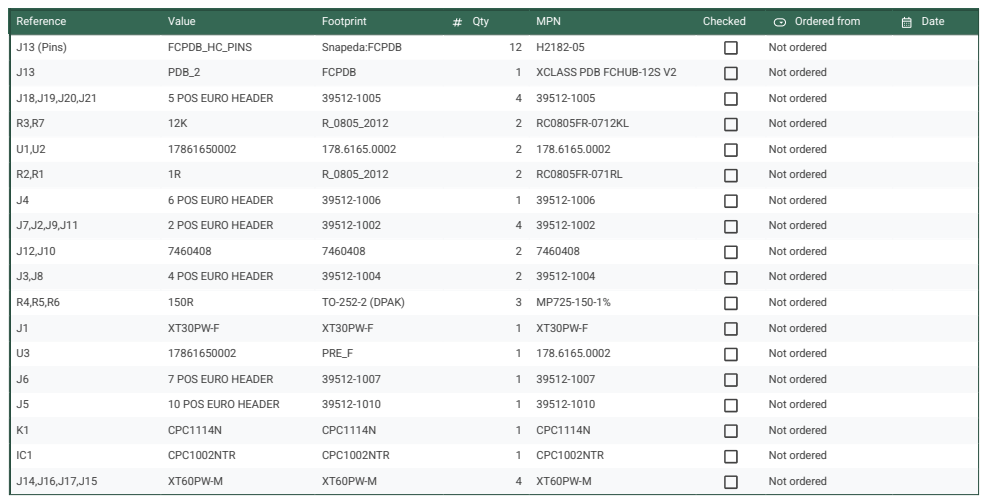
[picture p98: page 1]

Reference | Value | Footprint | Qty | MPN | Checked | Ordered from | Date

J13 (Pins) | FCPDB_HC_PINS | Snapeda:FCPDB | 12 | H2182-05 | | Not ordered

J13 | PDB_2 | FCPDB | 1 | XCLASS PDB FCHUB-12S V2 | | Not ordered

J18,J19,J20,J21 | 5 POS EURO HEADER | 39512-1005 | 4 | 39512-1005 | | Not ordered

R3,R7 | 12K | R_0805_2012 | 2 | RC0805FR-0712KL | | Not ordered

U1,U2 | 17861650002 | 178.6165.0002 | 2 | 178.6165.0002 | | Not ordered

R2,R1 | 1R | R_0805_2012 | 2 | RC0805FR-071RL | | Not ordered

J4 | 6 POS EURO HEADER | 39512-1006 | 1 | 39512-1006 | | Not ordered

J7,J2,J9,J11 | 2 POS EURO HEADER | 39512-1002 | 4 | 39512-1002 | | Not ordered

J12,J10 | 7460408 | 7460408 | 2 | 7460408 | | Not ordered

J3,J8 | 4 POS EURO HEADER | 39512-1004 | 2 | 39512-1004 | | Not ordered

R4,R5,R6 | 150R | TO-252-2 (DPAK) | 3 | MP725-150-1% | | Not ordered

J1 | XT30PW-F | XT30PW-F | 1 | XT30PW-F | | Not ordered

U3 | 17861650002 | PRE_F | 1 | 178.6165.0002 | | Not ordered

J6 | 7 POS EURO HEADER | 39512-1007 | 1 | 39512-1007 | | Not ordered

J5 | 10 POS EURO HEADER | 39512-1010 | 1 | 39512-1010 | | Not ordered

K1 | CPC1114N | CPC1114N | 1 | CPC1114N | | Not ordered

IC1 | CPC1002NTR | CPC1002NTR | 1 | CPC1002NTR | | Not ordered

J14,J16,J17,J15 | XT60PW-M | XT60PW-M | 4 | XT60PW-M | | Not ordered

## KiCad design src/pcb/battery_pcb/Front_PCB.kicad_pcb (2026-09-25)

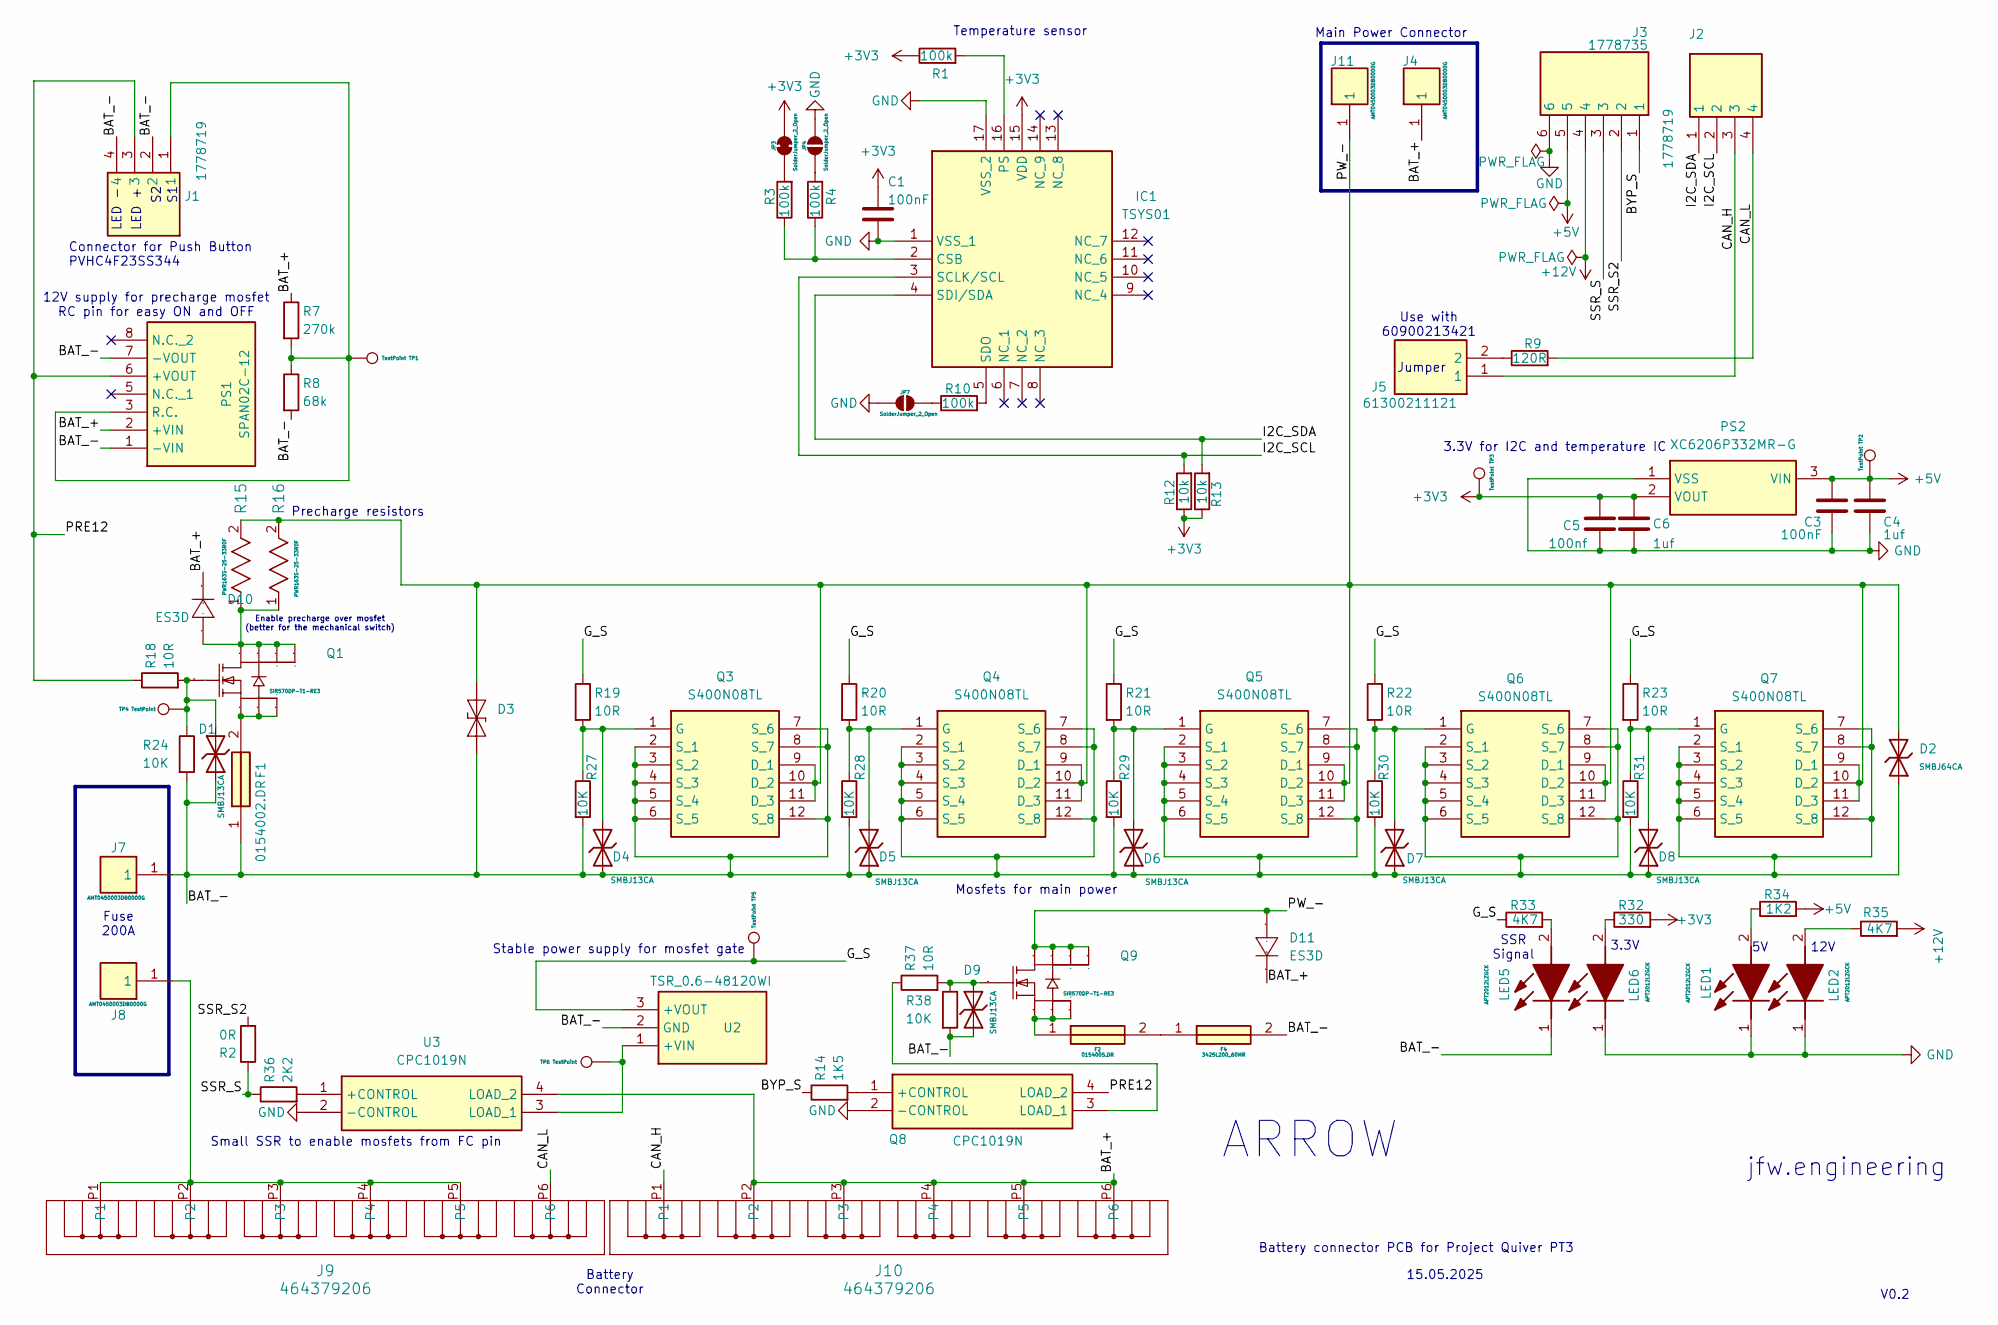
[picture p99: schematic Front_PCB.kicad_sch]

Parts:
C1, C3: 100nF; C_0805_2012Metric_Pad1.18x1.45mm_HandSolder
C4, C6: 1uf; C_0805_2012Metric_Pad1.18x1.45mm_HandSolder
C5: 100nf; C_0805_2012Metric_Pad1.18x1.45mm_HandSolder
D1, D4, D5, D6, D7, D8, D9: SMBJ13CA; D_SMB; Part SMBJ13CA; LCSC C19077568
D2: SMBJ64CA; D_SMB; Breakdown Voltage 78.6V; Part SMBJ64CA; LCSC C41376099
D3: SMC_L6.9-W5.9-LS7.9-BI; Manufacturer Part SMCJ75CA/TR13; LCSC Part Name SMCJ75CA/TR13
D10, D11: ES3D; D_SMC(DO-214AB); Manufacturer Part ES3D; LCSC Part Name ES3D
F1: 0154002.DR; 0154002DR; Mouser Part Number 576-0154002.DR
F2: 0154005.DR; 0154005DR; Mouser Part Number 576-0154005.DR
F4: 3425L200_60MR; FUSC8664X180N; Mouser Part Number 576-3425L200/60MR
IC1: TSYS01; QFN65P400X400X90-17N; Mouser Part Number 824-TSYS01
J1, J2: 1778719; Mouser Part Number 651-1778719
J3: 1778735; Mouser Part Number 651-1778735
J4, J7, J8, J11: AMT0450003DB0000G; Mouser Part Number 523-AMT0450003DB000G
J5: 61300211121; HDRV2W110P0X254_1X2_508X254X854P; Mouser Part Number 710-61300211121
J9, J10: 464379206; CONN_SD-46437-9000_06_MOL
JP3: SolderJumper_2_Open; SolderJumper-2_P1.3mm_Bridged2Bar_RoundedPad1.0x1.5mm
JP4, JP7: SolderJumper_2_Open; SolderJumper-2_P1.3mm_Open_RoundedPad1.0x1.5mm
LED1, LED2, LED5, LED6: APT2012LZGCK; LEDC2012X85N; Mouser Part Number 604-APT2012LZGCK
PS1: SPAN02C-12; SPAN02C12; Mouser Part Number 709-SPAN02C-12
PS2: XC6206P332MR-G; SOT95P280X130-3N; Mouser Part Number 865-XC6206P332MR-G
Q1, Q9: SIR570DP-T1-RE3; POWERPAK-SO-8_L5.9-W4.9-P1.27-LS6.2-BL; Mouser Part Number 781-SIR804DP-T1-GE3
Q3, Q4, Q5, Q6, Q7: S400N08TL; IAUT150N10S5N035ATMA1; Mouser Part Number 726-IPT017N12NM6ATMA
Q8: CPC1019N; SOP254P610X218-4N; Mouser Part Number 849-CPC1019N
R1, R3, R4, R10: 100k; R_0805_2012Metric_Pad1.20x1.40mm_HandSolder
R2: 0R; R_0805_2012Metric_Pad1.20x1.40mm_HandSolder
R7: 270k; R_0805_2012Metric_Pad1.20x1.40mm_HandSolder
R8: 68k; R_0805_2012Metric_Pad1.20x1.40mm_HandSolder
R9: 120R; R_0805_2012Metric_Pad1.20x1.40mm_HandSolder
R12, R13: 10k; R_0805_2012Metric_Pad1.20x1.40mm_HandSolder
R14: 1K5; R_0805_2012Metric_Pad1.20x1.40mm_HandSolder
R15, R16: PWR163S-25-33R0F; RES_PWR163_BRN; PARTREV 0716
R18, R19, R20, R21, R22, R23, R37: 10R; R_0805_2012Metric_Pad1.20x1.40mm_HandSolder
R24, R27, R28, R29, R30, R31, R38: 10K; R_0805_2012Metric_Pad1.20x1.40mm_HandSolder
R32: 330; R_0805_2012Metric_Pad1.20x1.40mm_HandSolder
R33, R35: 4K7; R_0805_2012Metric_Pad1.20x1.40mm_HandSolder
R34: 1K2; R_0805_2012Metric_Pad1.20x1.40mm_HandSolder
R36: 2K2; R_0805_2012Metric_Pad1.20x1.40mm_HandSolder
TP1, TP2, TP3, TP4, TP5, TP6: TestPoint; TestPoint_Pad_D1.5mm
U2: TSR_0.6-48120WI; TSR0648120WI; Mouser Part Number 495-TSR0.6-48120WI
U3: CPC1019N; SOP254P610X218-4N; Mouser Part Number 849-CPC1019N

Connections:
+3V3: C1.1, C5.1, C6.1, IC1.15 (VDD), JP3.2 (B), PS2.2 (VOUT), R1.1, R12.1, R13.1, R32.2, TP3.1
+5V: C3.1, C4.1, J3.5, PS2.3 (VIN), R34.2, TP2.1
+12V: J3.4, R35.2
/BAT_+: D10.1, D11.1, J4.1, J10.P2, J10.P3, J10.P4, J10.P5, J10.P6, PS1.2 (+VIN), R7.1, U3.4 (LOAD_2)
/BAT_-: D1.1, D2.1, D3.1 (K), D4.1, D5.1, D6.1, D7.1, D8.1, D9.1, F1.1, F4.2, J1.2, J1.4, J7.1, LED5.1 (K), PS1.1 (-VIN), PS1.7 (-VOUT), Q3.2 (S_1), Q3.3 (S_2), Q3.4 (S_3), Q3.5 (S_4), Q3.6 (S_5), Q3.7 (S_6), Q3.8 (S_7), Q3.12 (S_8), Q4.2 (S_1), Q4.3 (S_2), Q4.4 (S_3), Q4.5 (S_4), Q4.6 (S_5), Q4.7 (S_6), Q4.8 (S_7), Q4.12 (S_8), Q5.2 (S_1), Q5.3 (S_2), Q5.4 (S_3), Q5.5 (S_4), Q5.6 (S_5), Q5.7 (S_6), Q5.8 (S_7), Q5.12 (S_8), Q6.2 (S_1), Q6.3 (S_2), Q6.4 (S_3), Q6.5 (S_4), Q6.6 (S_5), Q6.7 (S_6), Q6.8 (S_7), Q6.12 (S_8), Q7.2 (S_1), Q7.3 (S_2), Q7.4 (S_3), Q7.5 (S_4), Q7.6 (S_5), Q7.7 (S_6), Q7.8 (S_7), Q7.12 (S_8), R8.2, R24.2, R27.2, R28.2, R29.2, R30.2, R31.2, R38.2, U2.2 (GND)
/BYP_S: J3.1, R14.1
/CAN_H: J2.3, J5.1, J10.P1
/CAN_L: J2.4, J9.P6, R9.2
/G_S: R19.1, R20.1, R21.1, R22.1, R23.1, R33.1, TP5.1, U2.3 (+VOUT)
/I2C_SCL: IC1.3 (SCLK/SCL), J2.2, R12.2
/I2C_SDA: IC1.4 (SDI/SDA), J2.1, R13.2
/PRE12: J1.3, PS1.6 (+VOUT), Q8.4 (LOAD_2), R18.1
/PW_-: D2.2, D3.2 (A), D11.2, J11.1, Q3.9 (D_1), Q3.10 (D_2), Q3.11 (D_3), Q4.9 (D_1), Q4.10 (D_2), Q4.11 (D_3), Q5.9 (D_1), Q5.10 (D_2), Q5.11 (D_3), Q6.9 (D_1), Q6.10 (D_2), Q6.11 (D_3), Q7.9 (D_1), Q7.10 (D_2), Q7.11 (D_3), Q9.5 (D), Q9.6 (D), Q9.7 (D), Q9.8 (D), R15.2, R16.2
/SSR_S: J3.3, R2.1, R36.1
/SSR_S2: J3.2, R2.2
GND: C1.2, C3.2, C4.2, C5.2, C6.2, IC1.1 (VSS_1), IC1.17 (VSS_2), J3.6, JP4.2 (B), JP7.1 (A), LED1.1 (K), LED2.1 (K), LED6.1 (K), PS2.1 (VSS), Q8.2 (-CONTROL), U3.2 (-CONTROL)
unnamed: D10.2, Q1.5 (D), Q1.6 (D), Q1.7 (D), Q1.8 (D), R15.1, R16.1
unnamed: F1.2, Q1.1 (S), Q1.2 (S), Q1.3 (S)
unnamed: F2.1, Q9.1 (S), Q9.2 (S), Q9.3 (S)
unnamed: F2.2, F4.1
unnamed: IC1.2 (CSB), R3.1, R4.1
unnamed: IC1.16 (PS), R1.2
unnamed: IC1.5 (SDO), R10.2
unnamed: J5.2, R9.1
unnamed: J8.1, J9.P1, J9.P2, J9.P3, J9.P4, J9.P5
unnamed: JP3.1 (A), R3.2
unnamed: JP4.1 (A), R4.2
unnamed: JP7.2 (B), R10.1
unnamed: LED1.2 (A), R34.1
unnamed: LED2.2 (A), R35.1
unnamed: LED5.2 (A), R33.2
unnamed: LED6.2 (A), R32.1
unnamed: J1.1, PS1.3 (R.C.), R7.2, R8.1, TP1.1
unnamed: D1.2, Q1.4 (G), R18.2, R24.1, TP4.1
unnamed: D4.2, Q3.1 (G), R19.2, R27.1
unnamed: D5.2, Q4.1 (G), R20.2, R28.1
unnamed: D6.2, Q5.1 (G), R21.2, R29.1
unnamed: D7.2, Q6.1 (G), R22.2, R30.1
unnamed: D8.2, Q7.1 (G), R23.2, R31.1
unnamed: Q8.1 (+CONTROL), R14.2
unnamed: Q8.3 (LOAD_1), R37.1
unnamed: D9.2, Q9.4 (G), R37.2, R38.1
unnamed: TP6.1, U2.1 (+VIN), U3.3 (LOAD_1)
unnamed: R36.2, U3.1 (+CONTROL)

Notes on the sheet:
15.05.2025
Connector for Push Button PVHC4F23SS344
Battery connector PCB for Project Quiver PT3
SSR Signal
3.3V
12V supply for precharge mosfet RC pin for easy ON and OFF
Use with 60900213421
12V
Battery Connector
ARROW
Temperature sensor
Small SSR to enable mosfets from FC pin
3.3V for I2C and temperature IC
Jumper
Mosfets for main power
LED -
Stable power supply for mosfet gate
V0.2
jfw.engineering
Enable precharge over mosfet (better for the mechanical switch)
LED +
Main Power Connector
Fuse 200A
Precharge resistors

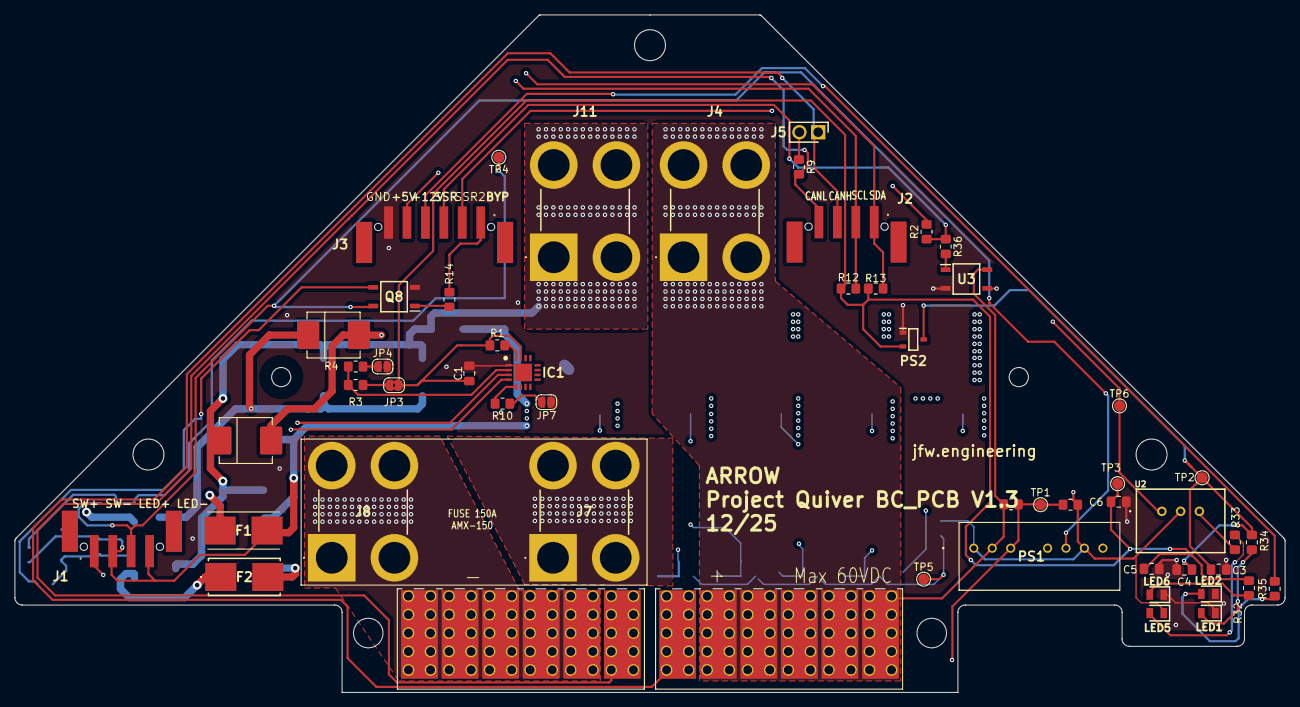
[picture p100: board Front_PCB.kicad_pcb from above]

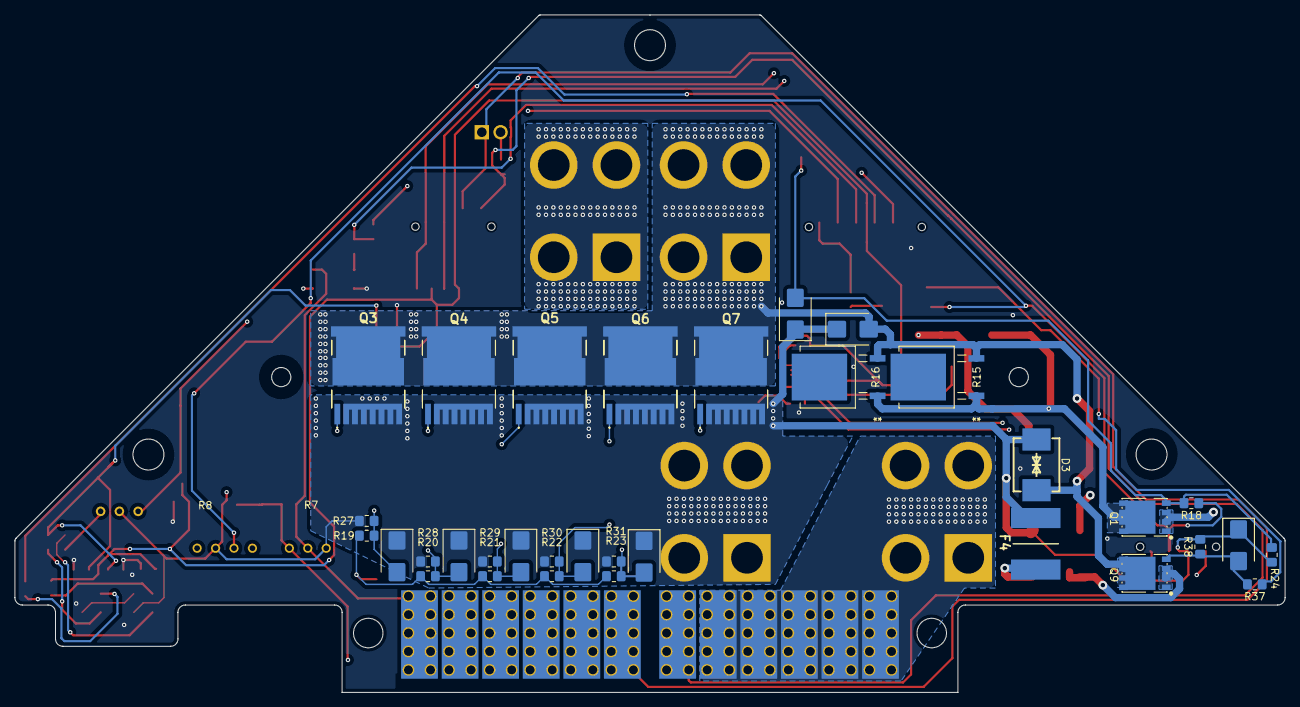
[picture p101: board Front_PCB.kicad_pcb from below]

Board: 4 copper layers, 172.2 x 91.8 mm, 87 parts (33 on the bottom side), 44 nets.

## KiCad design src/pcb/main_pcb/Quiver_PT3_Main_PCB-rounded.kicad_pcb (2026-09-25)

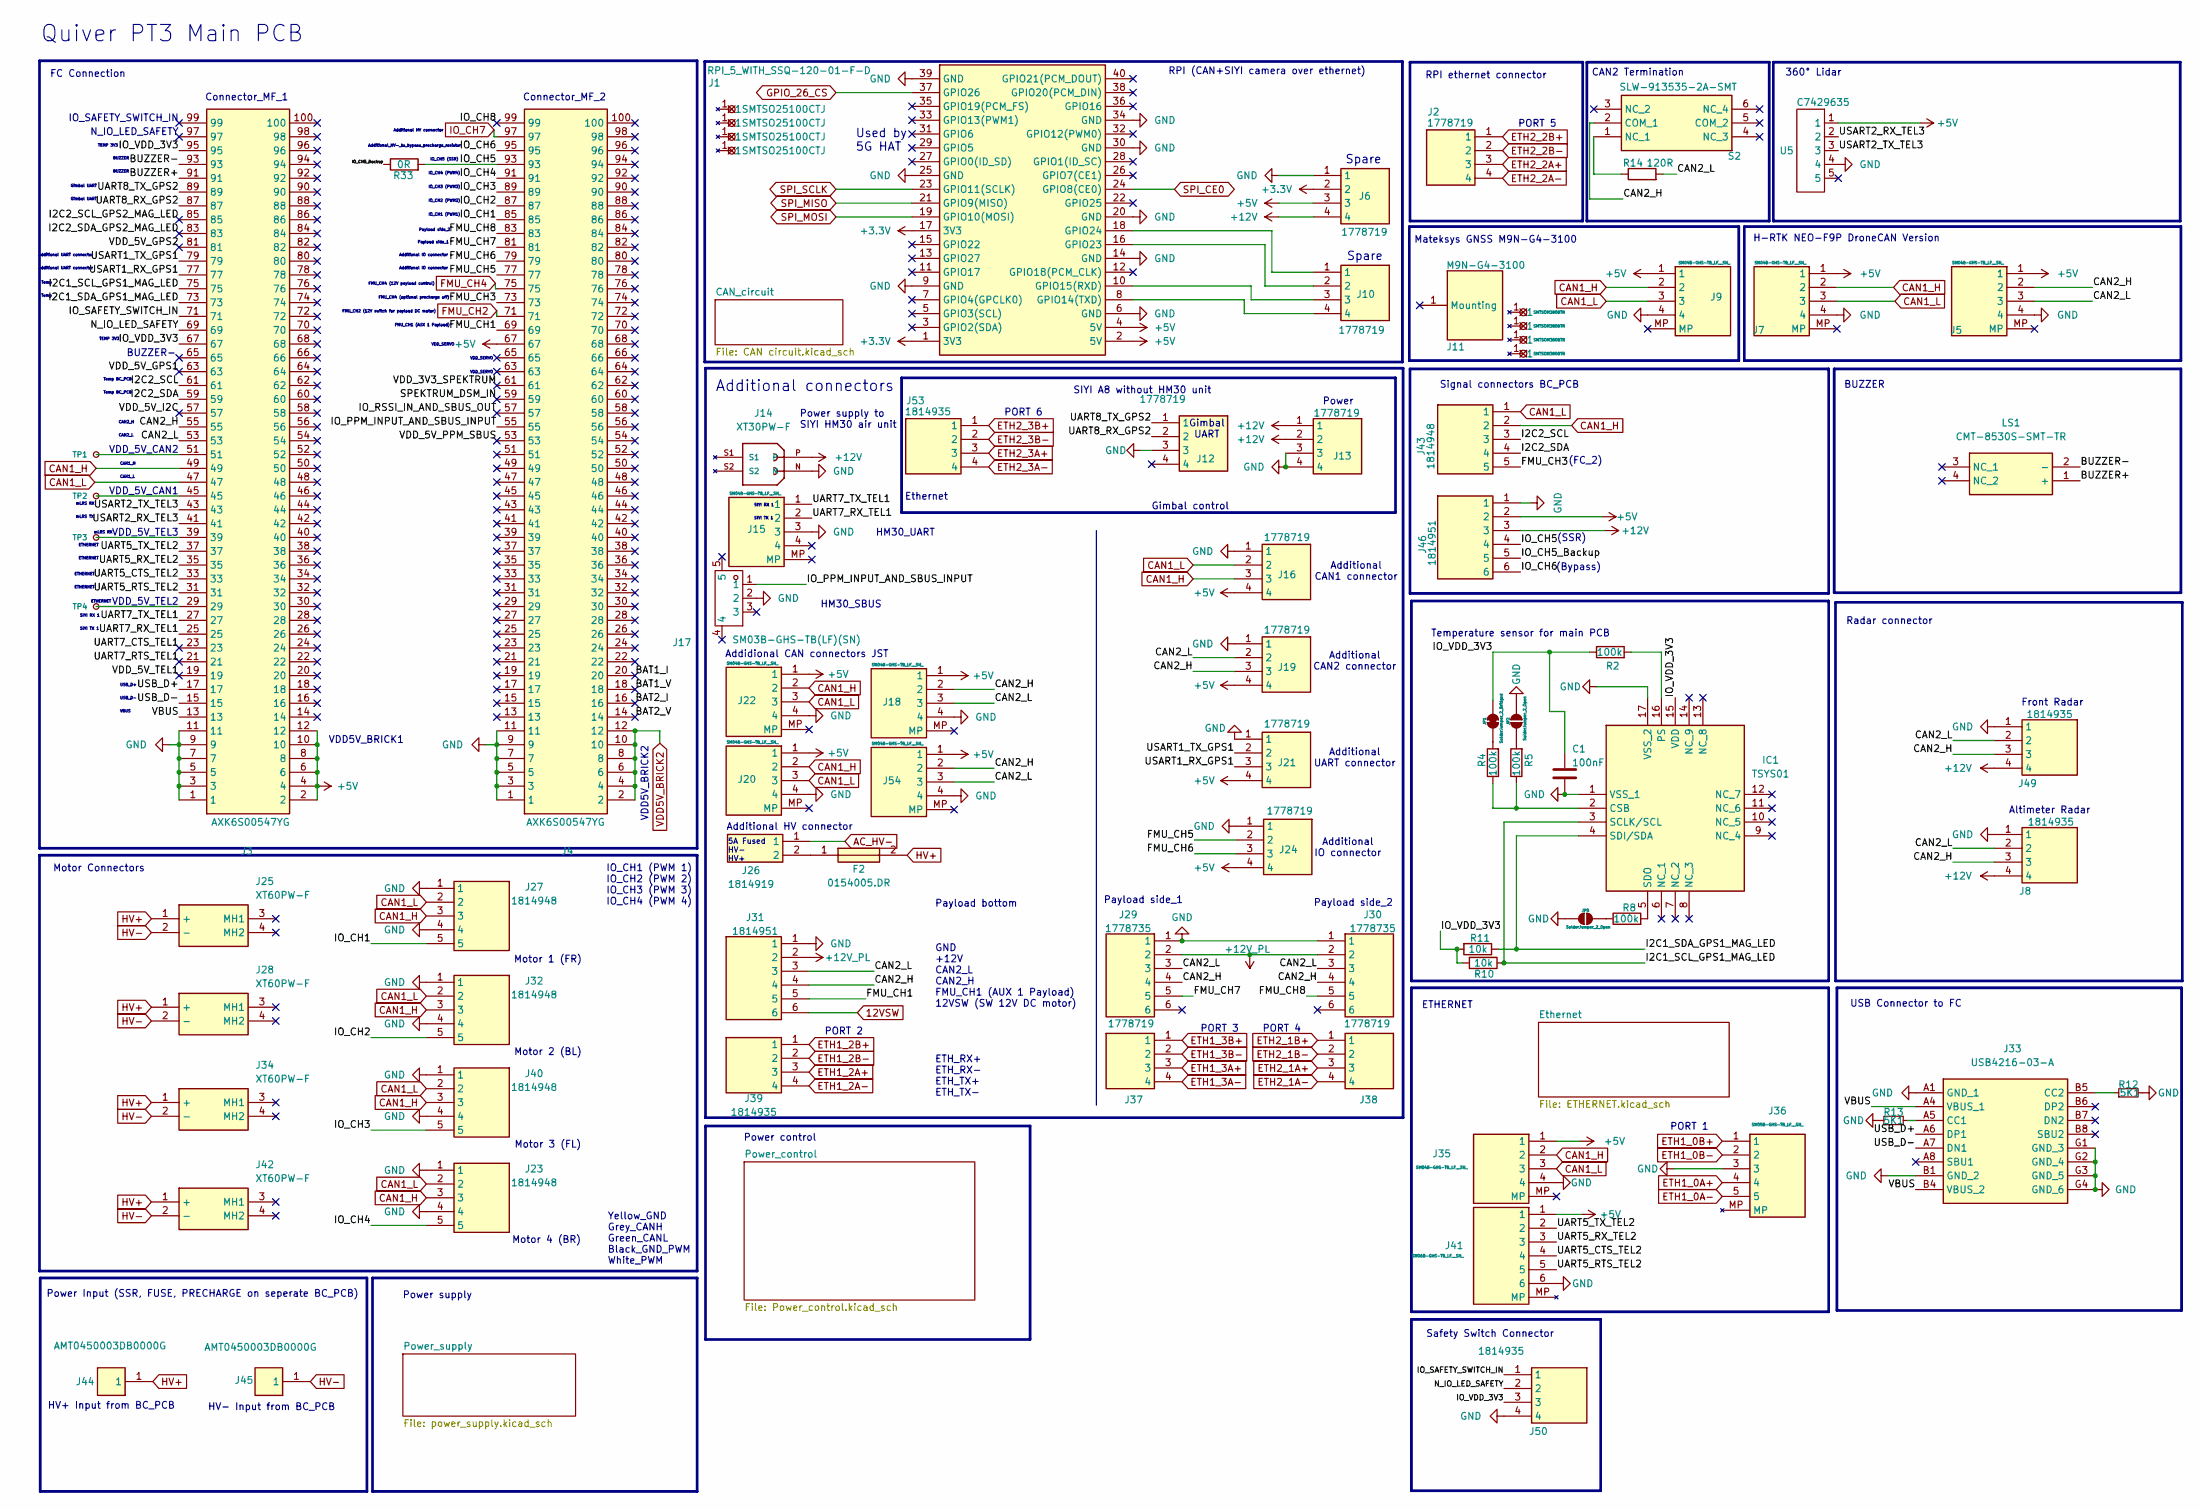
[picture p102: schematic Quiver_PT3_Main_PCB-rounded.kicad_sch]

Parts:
C1: 100nF; C_0805_2012Metric_Pad1.18x1.45mm_HandSolder; MPN CC0805KRX7R9BB104
F2: 0154005.DR; 0154005DR; Mouser Part Number 576-0154005.DR
IC1: TSYS01; QFN65P400X400X90-17N; Mouser Part Number 824-TSYS01
J1: RPI_5_WITH_SSQ-120-01-F-D; SSM-120-XXX-DV; Mouser Part Number 200-SSQ12001FD
J2, J6, J10, J12, J13, J16, J19, J21, J24, J37, J38: 1778719; Mouser Part Number 651-1778719
J3, J4: AXK6S00547YG; MANUFACTURER_PART_NUMBER AXK5S00347YG; Mouser Part Number 769-AXK6S00547YG
J5, J7, J9, J15, J18, J20, J22, J35, J54: SM04B-GHS-TB_LF__SN_; SM04B-GHS-TB; Mouser Part Number N/A
J8, J39, J49, J50, J53: 1814935; Mouser Part Number 651-1814935
J11: M9N-G4-3100; Manufacturer_Part_Number SSQ-104-01-L-D
J14: XT30PW-F; XT30PW-F_AMASS_XT30PW-F; PARTREV 1.2
J17: SM03B-GHS-TB(LF)(SN); CONN-TH_SM03B-GHS-TB-LF-SN; Mouser Part Number 651-1814922
J23, J27, J32, J40, J43: 1814948; Mouser Part Number 651-1814948
J25, J28, J34, J42: XT60PW-F; XT60PWF; Manufacturer_Part_Number XT60PW-F
J26: 1814919; Mouser Part Number 651-1814919
J29, J30: 1778735; Mouser Part Number 651-1778735
J31, J46: 1814951; Mouser Part Number 651-1814951
J33: USB4216-03-A; USB421603A; Mouser Part Number 640-USB4216-03-A
J36: SM05B-GHS-TB_LF__SN_; SM05B-GHS-TB; Mouser Part Number N/A
J41: SM06B-GHS-TB_LF__SN_; SM06B-GHS-TB; Mouser Part Number N/A
J44, J45: AMT0450003DB0000G; Mouser Part Number 523-AMT0450003DB000G
JP1: SolderJumper_2_Bridged; SolderJumper-2_P1.3mm_Bridged2Bar_RoundedPad1.0x1.5mm
JP2, JP5: SolderJumper_2_Open; SolderJumper-2_P1.3mm_Open_RoundedPad1.0x1.5mm
LS1: CMT-8530S-SMT-TR; CMT8530SSMTTR; Mouser Part Number 490-CMT-8530S-SMT-TR
R2, R4, R5: 100k; R_0805_2012Metric_Pad1.20x1.40mm_HandSolder
R8: 100k; R_0805_2012Metric_Pad1.20x1.40mm_HandSolder; MPN RC0805FR-0710KL
R10, R11: 10k; R_0805_2012Metric_Pad1.20x1.40mm_HandSolder; MPN RC0805FR-0710KL
R12, R13: 5K1; R_0805_2012Metric_Pad1.20x1.40mm_HandSolder
R14: 120R; R_0805_2012Metric_Pad1.20x1.40mm_HandSolder; MPN RC0805FR-07120RL
R33: 0R; R_0805_2012Metric_Pad1.20x1.40mm_HandSolder
S2: SLW-913535-2A-SMT; SLW9135352ASMT; MPN SLW-913535-2A-SMT; Mouser Part Number 179-SLW-913535-2ASMT
TP1, TP2, TP3, TP4: TestPoint_Small; TestPoint_Pad_1.0x1.0mm
U3, U6, U7, U8: SMTSOM380BTR; SMD_BD6.0-D4.2; Manufacturer Part SMTSOM380BTR; LCSC Part Name YIYUAN(怡远) 电路板表贴圆螺母柱 PCB贴片连接器 M3x5.56xL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
U5: C7429635; CONN-TH_5P-P2.50_ZX-XH2.54-5PZZ; Mouser Part Number 651-1814935
U9, U10, U11, U12: SMTSO25100CTJ; SMD_BD5.6-L5.6-W5.6-D4.1; Manufacturer Part SMTSO25100CTJ; LCSC Part Name 雄和远景，电路板表贴圆螺母柱，M2.5X10，铜镀锡,1个

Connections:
12VSW: J31.6; also elsewhere on the board
+3.3V: J1.1 (3V3), J1.17 (3V3), J6.2; also elsewhere on the board
+5V: J1.2 (5V), J1.4 (5V), J3.2, J3.4, J3.6, J3.8, J3.10, J3.12, J4.67, J5.1, J6.3, J7.1, J9.1, J16.4, J18.1, J19.4, J20.1, J21.4, J22.1, J24.4, J35.1, J41.1, J46.2, J54.1, U5.1; also elsewhere on the board
+12V: J6.4, J8.4, J13.1, J13.2, J14.P, J46.3, J49.4; also elsewhere on the board
+12V_PL: J29.2, J30.2, J31.2; also elsewhere on the board
/ I2C2_SDA_GPS2_MAG_LED: J3.83
/BAT1_I: J4.20
/BAT1_V: J4.18
/BAT2_I: J4.16
/BAT2_V: J4.14
/BUZZER+: J3.91, LS1.1 (+)
/BUZZER-: J3.93, LS1.2 (-)
/CAN2_H: J3.55, J5.2, J8.3, J18.2, J19.3, J29.4, J30.4, J31.4, J49.3, J54.2, S2.2 (COM_1)
/CAN2_L: J3.53, J5.3, J8.2, J18.3, J19.2, J29.3, J30.3, J31.3, J49.2, J54.3, R14.2
/FMU_CH1: J4.69, J31.5
/FMU_CH3: J4.73, J43.5
/FMU_CH5: J4.77, J24.2
/FMU_CH6: J4.79, J24.3
/FMU_CH7: J4.81, J29.5
/FMU_CH8: J4.83, J30.5
/I2C1_SCL_GPS1_MAG_LED: IC1.3 (SCLK/SCL), J3.75, R10.1
/I2C1_SDA_GPS1_MAG_LED: IC1.4 (SDI/SDA), J3.73, R11.1
/I2C2_SCL: J3.61, J43.3
/I2C2_SCL_GPS2_MAG_LED: J3.85
/I2C2_SDA: J3.59, J43.4
/IO_CH1: J4.85, J27.5
/IO_CH2: J4.87, J32.5
/IO_CH3: J4.89, J40.5
/IO_CH4: J4.91, J23.5
/IO_CH5: J4.93, J46.4, R33.2
/IO_CH5_Backup: J46.5, R33.1
/IO_CH6: J4.95, J46.6
/IO_CH8: J4.99
/IO_PPM_INPUT_AND_SBUS_INPUT: J4.55, J17.1
/IO_RSSI_IN_AND_SBUS_OUT: J4.57
/IO_SAFETY_SWITCH_IN: J3.71, J50.1
/IO_VDD_3V3: C1.1, IC1.15 (VDD), J3.67, J3.95, J50.3, JP1.2 (B), R2.1, R10.2, R11.2
/N_IO_LED_SAFETY: J3.69, J50.2
/SPEKTRUM_DSM_IN: J4.59
/UART5_CTS_TEL2: J3.33, J41.4
/UART5_RTS_TEL2: J3.31, J41.5
/UART5_RX_TEL2: J3.35, J41.3
/UART5_TX_TEL2: J3.37, J41.2
/UART7_CTS_TEL1: J3.23
/UART7_RTS_TEL1: J3.21
/UART7_RX_TEL1: J3.25, J15.2
/UART7_TX_TEL1: J3.27, J15.1
/UART8_RX_GPS2: J3.87, J12.2
/UART8_TX_GPS2: J3.89, J12.1
/USART1_RX_GPS1: J3.77, J21.3
/USART1_TX_GPS1: J3.79, J21.2
/USART2_RX_TEL3: J3.41, U5.2
/USART2_TX_TEL3: J3.43, U5.3
/USB_D+: J3.17, J33.A6 (DP1)
/USB_D-: J3.15, J33.A7 (DN1)
/VBUS: J3.13, J33.A4 (VBUS_1), J33.B4 (VBUS_2)
/VDD_3V3_SPEKTRUM: J4.61
/VDD_5V_GPS1: J3.63
/VDD_5V_GPS2: J3.81
/VDD_5V_I2C: J3.57
/VDD_5V_PPM_SBUS: J4.53
/VDD_5V_TEL1: J3.19
AC_HV-: J26.1; also elsewhere on the board
CAN1_H: J3.49, J7.2, J9.2, J16.3, J20.2, J22.2, J23.3, J27.3, J32.3, J35.2, J40.3, J43.2; also elsewhere on the board
CAN1_L: J3.47, J7.3, J9.3, J16.2, J20.3, J22.3, J23.2, J27.2, J32.2, J35.3, J40.2, J43.1; also elsewhere on the board
ETH1_0A+: J36.4; also elsewhere on the board
ETH1_0A-: J36.5; also elsewhere on the board
ETH1_0B+: J36.1; also elsewhere on the board
ETH1_0B-: J36.2; also elsewhere on the board
ETH1_2A+: J39.3; also elsewhere on the board
ETH1_2A-: J39.4; also elsewhere on the board
ETH1_2B+: J39.1; also elsewhere on the board
ETH1_2B-: J39.2; also elsewhere on the board
ETH1_3A+: J37.3; also elsewhere on the board
ETH1_3A-: J37.4; also elsewhere on the board
ETH1_3B+: J37.1; also elsewhere on the board
ETH1_3B-: J37.2; also elsewhere on the board
ETH2_1A+: J38.3; also elsewhere on the board
ETH2_1A-: J38.4; also elsewhere on the board
ETH2_1B+: J38.1; also elsewhere on the board
ETH2_1B-: J38.2; also elsewhere on the board
ETH2_2A+: J2.3; also elsewhere on the board
ETH2_2A-: J2.4; also elsewhere on the board
ETH2_2B+: J2.1; also elsewhere on the board
ETH2_2B-: J2.2; also elsewhere on the board
ETH2_3A+: J53.3; also elsewhere on the board
ETH2_3A-: J53.4; also elsewhere on the board
ETH2_3B+: J53.1; also elsewhere on the board
ETH2_3B-: J53.2; also elsewhere on the board
FMU_CH2: J4.71; also elsewhere on the board
FMU_CH4: J4.75; also elsewhere on the board
GND: C1.2, IC1.1 (VSS_1), IC1.17 (VSS_2), J1.6 (GND), J1.9 (GND), J1.14 (GND), J1.20 (GND), J1.25 (GND), J1.30 (GND), J1.34 (GND), J1.39 (GND), J3.1, J3.3, J3.5, J3.7, J3.9, J3.11, J4.1, J4.3, J4.5, J4.7, J4.9, J4.11, J5.4, J6.1, J7.4, J8.1, J9.4, J12.3, J13.3, J13.4, J14.N, J15.3, J16.1, J17.2, J18.4, J19.1, J20.4, J21.1, J22.4, J23.1, J23.4, J24.1, J27.1, J27.4, J29.1, J30.1, J31.1, J32.1, J32.4, J33.A1 (GND_1), J33.B1 (GND_2), J33.G1 (GND_3), J33.G2 (GND_4), J33.G3 (GND_5), J33.G4 (GND_6), J35.4, J36.3, J40.1, J40.4, J41.6, J46.1, J49.1, J50.4, J54.4, JP2.2 (B), JP5.1 (A), R12.2, R13.1, U5.4; also elsewhere on the board
GPIO_26_CS: J1.37 (GPIO26); also elsewhere on the board
HV+: F2.2, J25.1 (+), J28.1 (+), J34.1 (+), J42.1 (+), J44.1; also elsewhere on the board
HV-: J25.2 (-), J28.2 (-), J34.2 (-), J42.2 (-), J45.1; also elsewhere on the board
IO_CH7: J4.97; also elsewhere on the board
unnamed: F2.1, J26.2
unnamed: IC1.2 (CSB), R4.1, R5.1
unnamed: IC1.16 (PS), R2.2
unnamed: IC1.5 (SDO), R8.2
unnamed: J1.8 (GPIO14(TXD)), J10.4
unnamed: J1.10 (GPIO15(RXD)), J10.3
unnamed: J1.16 (GPIO23), J10.2
unnamed: J1.18 (GPIO24), J10.1
unnamed: J3.29, TP4.1
unnamed: J3.39, TP3.1
unnamed: J3.45, TP2.1
unnamed: J3.51, TP1.1
unnamed: J33.A5 (CC1), R13.2
unnamed: J33.B5 (CC2), R12.1
unnamed: JP1.1 (A), R4.2
unnamed: JP2.1 (A), R5.2
unnamed: JP5.2 (B), R8.1
unnamed: R14.1, S2.1 (NC_1)
SPI_CE0: J1.24 (GPIO8(CE0)); also elsewhere on the board
SPI_MISO: J1.21 (GPIO9(MISO)); also elsewhere on the board
SPI_MOSI: J1.19 (GPIO10(MOSI)); also elsewhere on the board
SPI_SCLK: J1.23 (GPIO11(SCLK)); also elsewhere on the board
VDD5V_BRICK2: J4.2, J4.4, J4.6, J4.8, J4.10, J4.12; also elsewhere on the board

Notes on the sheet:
ETHERNET
Altimeter Radar
TEMP 3V3
IO_CH2 (PWM2)
Additional CAN2 connector
Additional HV connector
PORT 5
Motor Connectors
Motor 4 (BR)
FMU_CH4 (optional precharge off)
FC Connection
Motor 2 (BL)
FMU_CH4 (12V payload control)
BUZZER BUZZER
Used by 5G HAT
Temperature sensor for main PCB
Power Input (SSR, FUSE, PRECHARGE on seperate BC_PCB)
USB_D+ USB_D- VBUS
PORT 4
ETHERNET ETHERNET
FMU_CH2 (12V switch for payload DC motor)
Payload side_2
(Bypass)
IO_CH5 (SSR)
PORT 3
Connector_MF_2
N_IO_LED_SAFETY
CAN2 Termination
HM30_SBUS
VDD5V_BRICK1
FMU_CH1 (AUX 1 Payload)
USB Connector to FC
VDD5V_BRICK2
(FC_2)
Power
VDD_SERVO
RPI (CAN+SIYI camera over ethernet)
IO_CH4 (PWM4)
Gimbal UART Gimbal UART
Power supply

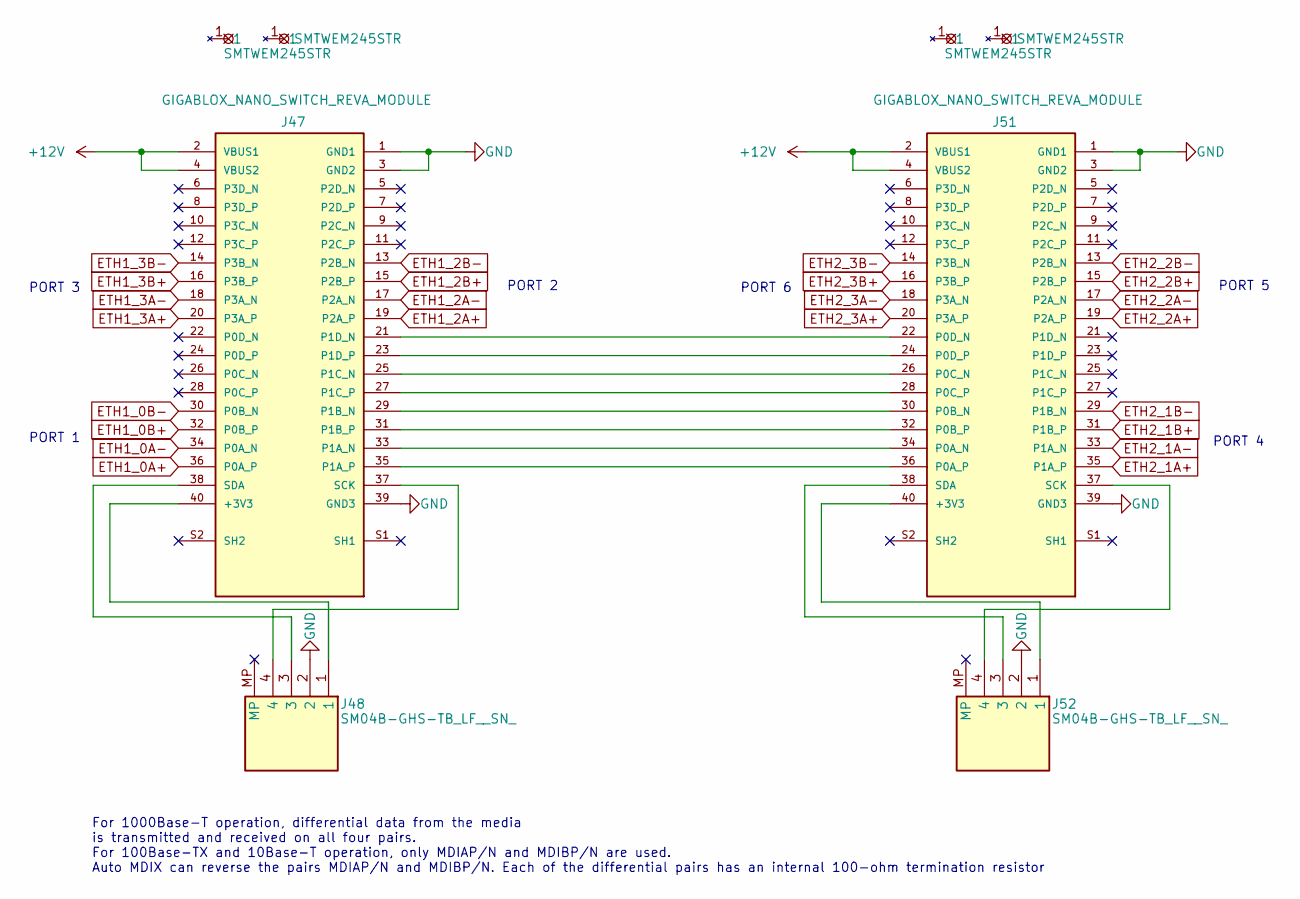
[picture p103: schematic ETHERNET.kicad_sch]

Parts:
J47, J51: GIGABLOX_NANO_SWITCH_REVA_MODULE; GIGABLOX_NANO_SWITCH_REVA_MODULE_LSHM-120-02.5-L-DV-A-S-K-TR; Mouser Part Number 200-LSHM1202.5LDVASK
J48, J52: SM04B-GHS-TB_LF__SN_; SM04B-GHS-TB; Mouser Part Number N/A
U13, U14, U15, U16: SMTWEM245STR; SCREW-SMD_BD4.4-D2.8-H4.5; Manufacturer Part SMTWEM245STR; LCSC Part Name YIYUAN(怡远) 电路板表贴圆螺母柱 PCB贴片连接器 M2x4.35xL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

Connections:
+12V: J47.2 (VBUS1), J47.4 (VBUS2), J51.2 (VBUS1), J51.4 (VBUS2); also elsewhere on the board
ETH1_0A+: J47.36 (P0A_P); also elsewhere on the board
ETH1_0A-: J47.34 (P0A_N); also elsewhere on the board
ETH1_0B+: J47.32 (P0B_P); also elsewhere on the board
ETH1_0B-: J47.30 (P0B_N); also elsewhere on the board
ETH1_2A+: J47.19 (P2A_P); also elsewhere on the board
ETH1_2A-: J47.17 (P2A_N); also elsewhere on the board
ETH1_2B+: J47.15 (P2B_P); also elsewhere on the board
ETH1_2B-: J47.13 (P2B_N); also elsewhere on the board
ETH1_3A+: J47.20 (P3A_P); also elsewhere on the board
ETH1_3A-: J47.18 (P3A_N); also elsewhere on the board
ETH1_3B+: J47.16 (P3B_P); also elsewhere on the board
ETH1_3B-: J47.14 (P3B_N); also elsewhere on the board
ETH2_1A+: J51.35 (P1A_P); also elsewhere on the board
ETH2_1A-: J51.33 (P1A_N); also elsewhere on the board
ETH2_1B+: J51.31 (P1B_P); also elsewhere on the board
ETH2_1B-: J51.29 (P1B_N); also elsewhere on the board
ETH2_2A+: J51.19 (P2A_P); also elsewhere on the board
ETH2_2A-: J51.17 (P2A_N); also elsewhere on the board
ETH2_2B+: J51.15 (P2B_P); also elsewhere on the board
ETH2_2B-: J51.13 (P2B_N); also elsewhere on the board
ETH2_3A+: J51.20 (P3A_P); also elsewhere on the board
ETH2_3A-: J51.18 (P3A_N); also elsewhere on the board
ETH2_3B+: J51.16 (P3B_P); also elsewhere on the board
ETH2_3B-: J51.14 (P3B_N); also elsewhere on the board
GND: J47.1 (GND1), J47.3 (GND2), J47.39 (GND3), J48.2, J51.1 (GND1), J51.3 (GND2), J51.39 (GND3), J52.2; also elsewhere on the board
unnamed: J47.40 (+3V3), J48.1
unnamed: J47.33 (P1A_N), J51.34 (P0A_N)
unnamed: J47.35 (P1A_P), J51.36 (P0A_P)
unnamed: J47.29 (P1B_N), J51.30 (P0B_N)
unnamed: J47.31 (P1B_P), J51.32 (P0B_P)
unnamed: J47.25 (P1C_N), J51.26 (P0C_N)
unnamed: J47.27 (P1C_P), J51.28 (P0C_P)
unnamed: J47.21 (P1D_N), J51.22 (P0D_N)
unnamed: J47.23 (P1D_P), J51.24 (P0D_P)
unnamed: J47.37 (SCK), J48.4
unnamed: J47.38 (SDA), J48.3
unnamed: J51.40 (+3V3), J52.1
unnamed: J51.37 (SCK), J52.4
unnamed: J51.38 (SDA), J52.3

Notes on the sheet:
PORT 6
PORT 3
For 1000Base-T operation, differential data from the media is transmitted and received on all four pairs. For 100Base-TX and 10Base-T operation, only MDIAP/N and MDIBP/N are used. Auto MDIX can reverse the pairs MDIAP/N and MDIBP/N. Each of the differential pairs has an internal 100-ohm termination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
PORT 4
PORT 2
PORT 1
PORT 5

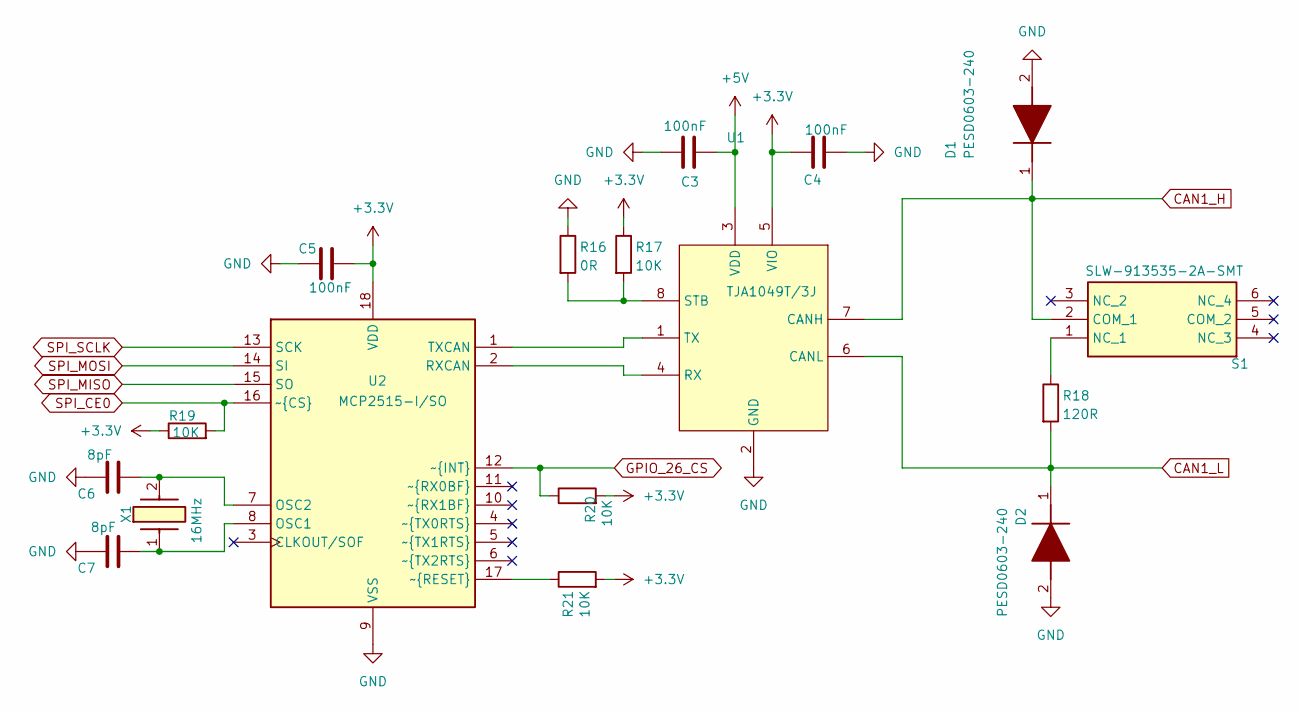
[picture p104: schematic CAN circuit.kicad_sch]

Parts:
C3, C4, C5: 100nF; C_0805_2012Metric_Pad1.18x1.45mm_HandSolder; MPN CC0805KRX7R9BB104
C6, C7: 8pF; C_0603_1608Metric_Pad1.08x0.95mm_HandSolder; MPN CC0603JRNPO9BN8R0
D1, D2: PESD0603-240; DIONC1608X55N; MPN PESD0603-240; Mouser Part Number 650-PESD0603-240
R16: 0R; R_0805_2012Metric_Pad1.20x1.40mm_HandSolder; MPN RC0805FR-070RL
R17, R19, R20, R21: 10K; R_0805_2012Metric_Pad1.20x1.40mm_HandSolder; MPN RC0805FR-0710KL
R18: 120R; R_0805_2012Metric_Pad1.20x1.40mm_HandSolder; MPN RC0805FR-07120RL
S1: SLW-913535-2A-SMT; SLW9135352ASMT; MPN SLW-913535-2A-SMT; Mouser Part Number 179-SLW-913535-2ASMT
U1: TJA1049T/3J; SOIC127P600X175-8N; MPN TJA1049T/3J; Mouser Part Number 771-TJA1049T/3J
U2: MCP2515-I/SO; SOIC127P1030X265-18N; MPN MCP2515-I/SO; Mouser Part Number 579-MCP2515-I/SO
X1: 16MHz; NX3225GB-16M-STD-CRA-2; MPN NX3225GB-16M-STD-CRA-2; Mouser Part Number 344-NX3225GB16MSTRA2

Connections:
+3.3V: C4.1, C5.2, R17.1, R19.1, R20.2, R21.2, U1.5 (VIO), U2.18 (VDD); also elsewhere on the board
+5V: C3.2, U1.3 (VDD); also elsewhere on the board
CAN1_H: D1.1 (K), S1.2 (COM_1), U1.7 (CANH); also elsewhere on the board
CAN1_L: D2.1 (K), R18.2, U1.6 (CANL); also elsewhere on the board
GND: C3.1, C4.2, C5.1, C6.1, C7.1, D1.2 (A), D2.2 (A), R16.1, U1.2 (GND), U2.9 (VSS); also elsewhere on the board
GPIO_26_CS: R20.1, U2.12 (~INT~{}); also elsewhere on the board
unnamed: R18.1, S1.1 (NC_1)
unnamed: U1.4 (RX), U2.2 (RXCAN)
unnamed: R16.2, R17.2, U1.8 (STB)
unnamed: U1.1 (TX), U2.1 (TXCAN)
unnamed: C7.2, U2.8 (OSC1), X1.1
unnamed: C6.2, U2.7 (OSC2), X1.2
unnamed: R21.1, U2.17 (~RESET~{})
SPI_CE0: R19.2, U2.16 (~CS~{}); also elsewhere on the board
SPI_MISO: U2.15 (SO); also elsewhere on the board
SPI_MOSI: U2.14 (SI); also elsewhere on the board
SPI_SCLK: U2.13 (SCK); also elsewhere on the board

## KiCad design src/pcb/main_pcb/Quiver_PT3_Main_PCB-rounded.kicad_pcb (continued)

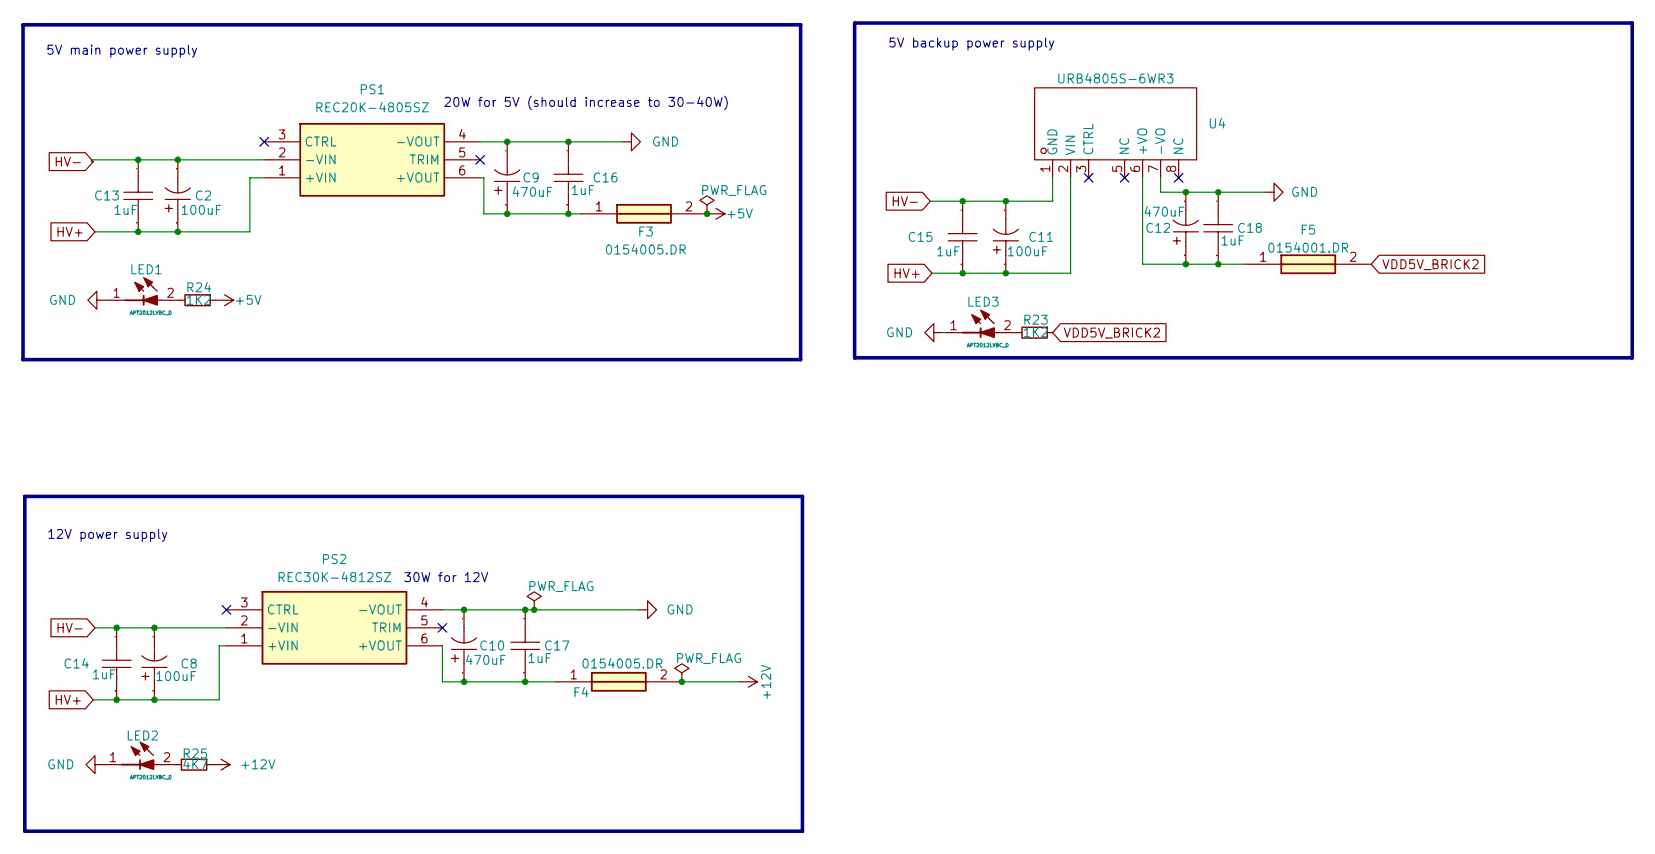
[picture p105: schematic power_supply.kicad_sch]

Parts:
C2, C8, C11: 100uF; CAP-TH_BD10.0-P5.00-D0.6-FD_2; Manufacturer Part 1011001013R00; LCSC Part Name 100uF ±20% 100V
C9, C10, C12: 470uF; CAP-TH_BD8.0-P3.50-D0.6-FD; Manufacturer Part SPT1EM471F12OR; LCSC Part Name 470uF ±20% 25V
C13, C14, C15, C16, C17, C18: 1uF; C1206; Manufacturer Part CL31B105KCHNNNE; LCSC Part Name 1uF ±10% 100V
F3, F4: 0154005.DR; 0154005DR; Mouser Part Number 576-0154005.DR
F5: 0154001.DR; 0154001DR; Mouser Part Number 576-0154001.DR
LED1, LED2, LED3: APT2012LVBC_D; LEDC2012X85N; Mouser Part Number 604-APT2012LVBCD
PS1: REC20K-4805SZ; REC20K; Manufacturer_Part_Number REC20K-4805SZ
PS2: REC30K-4812SZ; REC30K; Manufacturer_Part_Number REC30K-4812SZ
R23, R24: 1K2; R_0805_2012Metric_Pad1.20x1.40mm_HandSolder
R25: 4K7; R_0805_2012Metric_Pad1.20x1.40mm_HandSolder
U4: URB4805S-6WR3; PWRM-TH_YLPTEC_URBXXXXS-6WR3; Manufacturer Part URB4805S-6WR3; LCSC Part Name DC/DC电源模块 6W宽压输入，隔离稳压单路/正负双路输出

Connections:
+5V: F3.2, R24.1; also elsewhere on the board
+12V: F4.2, R25.1; also elsewhere on the board
GND: C9.2, C10.2, C12.2, C16.2, C17.2, C18.2, LED1.1 (K), LED2.1 (K), LED3.1 (K), PS1.4 (-VOUT), PS2.4 (-VOUT), U4.7 (-VO); also elsewhere on the board
HV+: C2.1, C8.1, C11.1, C13.1, C14.1, C15.1, PS1.1 (+VIN), PS2.1 (+VIN), U4.2 (VIN); also elsewhere on the board
HV-: C2.2, C8.2, C11.2, C13.2, C14.2, C15.2, PS1.2 (-VIN), PS2.2 (-VIN), U4.1 (GND); also elsewhere on the board
unnamed: LED1.2 (A), R24.2
unnamed: LED2.2 (A), R25.2
unnamed: LED3.2 (A), R23.2
unnamed: C9.1, C16.1, F3.1, PS1.6 (+VOUT)
unnamed: C10.1, C17.1, F4.1, PS2.6 (+VOUT)
unnamed: C12.1, C18.1, F5.1, U4.6 (+VO)
VDD5V_BRICK2: F5.2, R23.1; also elsewhere on the board

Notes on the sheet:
5V backup power supply
5V main power supply
30W for 12V
12V power supply
20W for 5V (should increase to 30-40W)

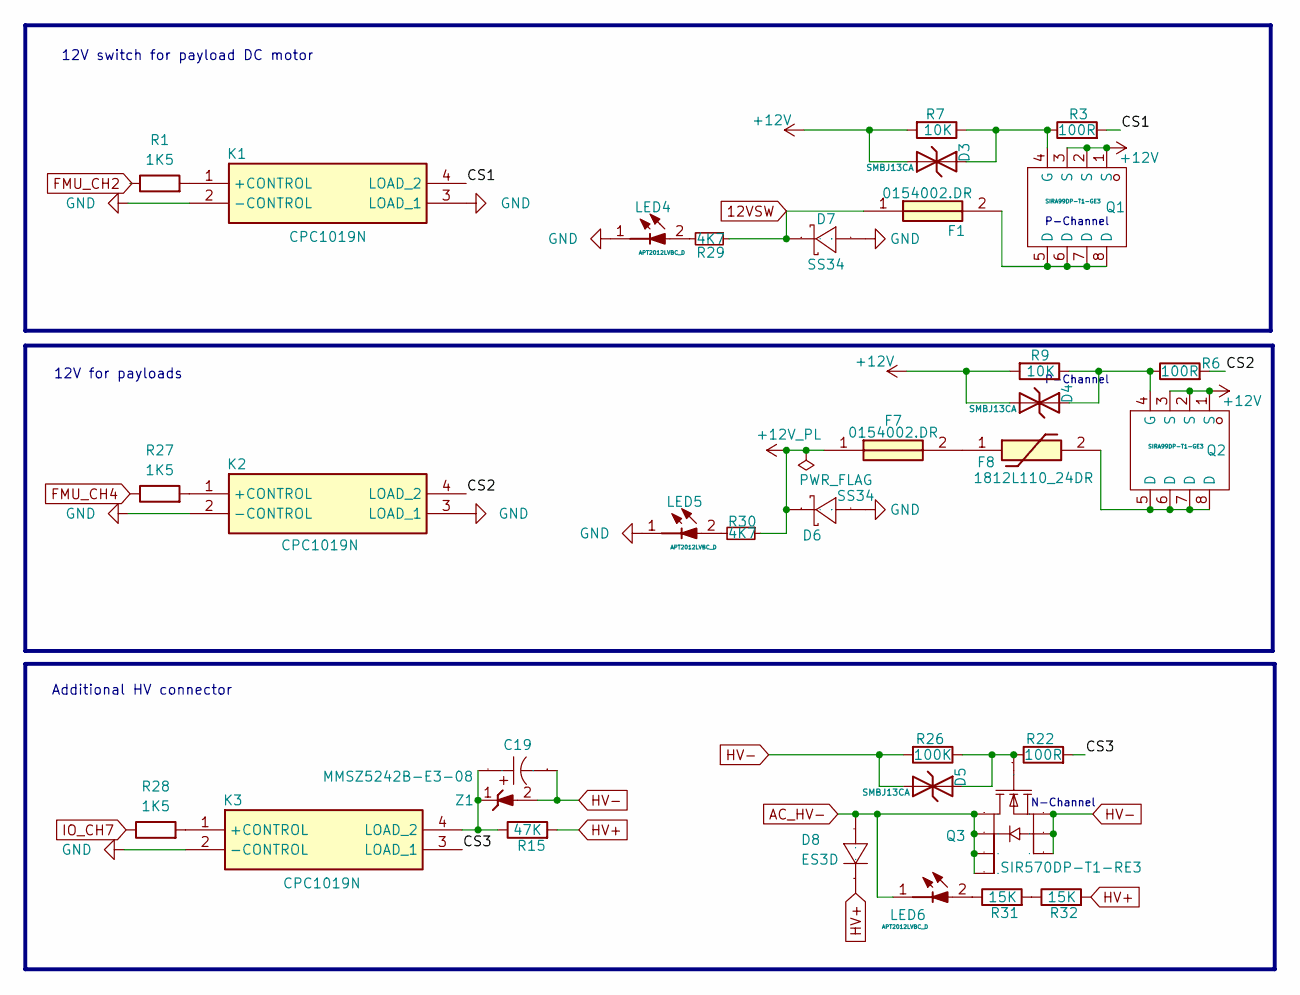
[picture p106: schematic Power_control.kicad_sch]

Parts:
C19: 22uF; CAP-SMD_L7.3-W4.3-RD_PA300LV227M0J; Manufacturer Part EEFCX1E220R; LCSC Part Name 22uF ±20% 25V
D3, D4, D5: SMBJ13CA; D_SMB; Part SMBJ13CA; LCSC C19077568
D6, D7: SS34; SMB_L4.6-W3.6-LS5.3-RD; Manufacturer Part SS34; LCSC Part Name 电压:40V 电流:3A
D8: ES3D; SMC_L7.1-W6.2-LS8.1-RD; Manufacturer Part ES3D; LCSC Part Name ES3D
F1, F7: 0154002.DR; 0154002DR; Mouser Part Number 576-0154002.DR
F8: 1812L110_24DR; 1812L010DR; Mouser Part Number 576-1812L110/24DR
K1, K2, K3: CPC1019N; SOP254P610X218-4N; Mouser Part Number 849-CPC1019N
LED4, LED5, LED6: APT2012LVBC_D; LEDC2012X85N; Mouser Part Number 604-APT2012LVBCD
Q1, Q2: SIRA99DP-T1-GE3; POWERPAK-SO-8_L5.9-W4.9-P1.27-LS6.2-BL; Mouser Part Number 781-SIR804DP-T1-GE3
Q3: SIR570DP-T1-RE3; POWERPAK-SO-8_L5.9-W4.9-P1.27-LS6.2-BL; Mouser Part Number 781-SIR804DP-T1-GE3
R1, R27, R28: 1K5; R_0805_2012Metric_Pad1.20x1.40mm_HandSolder
R3, R6, R22: 100R; R_0805_2012Metric_Pad1.20x1.40mm_HandSolder
R7, R9: 10K; R_0805_2012Metric_Pad1.20x1.40mm_HandSolder
R15: 47K; R_0805_2012Metric_Pad1.20x1.40mm_HandSolder
R26: 100K; R_0805_2012Metric_Pad1.20x1.40mm_HandSolder
R29, R30: 4K7; R_0805_2012Metric_Pad1.20x1.40mm_HandSolder
R31, R32: 15K; R_0805_2012Metric_Pad1.20x1.40mm_HandSolder
Z1: MMSZ5242B-E3-08; SOD3716X135N; Mouser Part Number 78-MMSZ5242B-E3-08

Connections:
12VSW: D7.1 (C), F1.1, R29.1; also elsewhere on the board
+12V: D3.1, D4.1, Q1.1 (S), Q1.2 (S), Q1.3 (S), Q2.1 (S), Q2.2 (S), Q2.3 (S), R7.2, R9.2; also elsewhere on the board
+12V_PL: D6.1 (C), F7.1, R30.1; also elsewhere on the board
/Power_control/CS1: K1.4 (LOAD_2), R3.2
/Power_control/CS2: K2.4 (LOAD_2), R6.2
/Power_control/CS3: K3.3 (LOAD_1), R22.2
AC_HV-: D8.2, LED6.1 (K), Q3.5 (D), Q3.6 (D), Q3.7 (D), Q3.8 (D); also elsewhere on the board
FMU_CH2: R1.1; also elsewhere on the board
FMU_CH4: R27.1; also elsewhere on the board
GND: D6.2 (A), D7.2 (A), K1.2 (-CONTROL), K1.3 (LOAD_1), K2.2 (-CONTROL), K2.3 (LOAD_1), K3.2 (-CONTROL), LED4.1 (K), LED5.1 (K); also elsewhere on the board
HV+: D8.1, R15.2, R32.2; also elsewhere on the board
HV-: C19.1, D5.1, Q3.1 (S), Q3.2 (S), Q3.3 (S), R26.2, Z1.2 (A); also elsewhere on the board
IO_CH7: R28.1; also elsewhere on the board
unnamed: F1.2, Q1.5 (D), Q1.6 (D), Q1.7 (D), Q1.8 (D)
unnamed: F7.2, F8.1
unnamed: F8.2, Q2.5 (D), Q2.6 (D), Q2.7 (D), Q2.8 (D)
unnamed: K1.1 (+CONTROL), R1.2
unnamed: K2.1 (+CONTROL), R27.2
unnamed: K3.1 (+CONTROL), R28.2
unnamed: C19.2, K3.4 (LOAD_2), R15.1, Z1.1 (K)
unnamed: LED4.2 (A), R29.2
unnamed: LED5.2 (A), R30.2
unnamed: LED6.2 (A), R31.1
unnamed: D3.2, Q1.4 (G), R3.1, R7.1
unnamed: D4.2, Q2.4 (G), R6.1, R9.1
unnamed: D5.2, Q3.4 (G), R22.1, R26.1
unnamed: R31.2, R32.1

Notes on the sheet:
Additional HV connector
12V switch for payload DC motor
P-Channel
N-Channel
12V for payloads

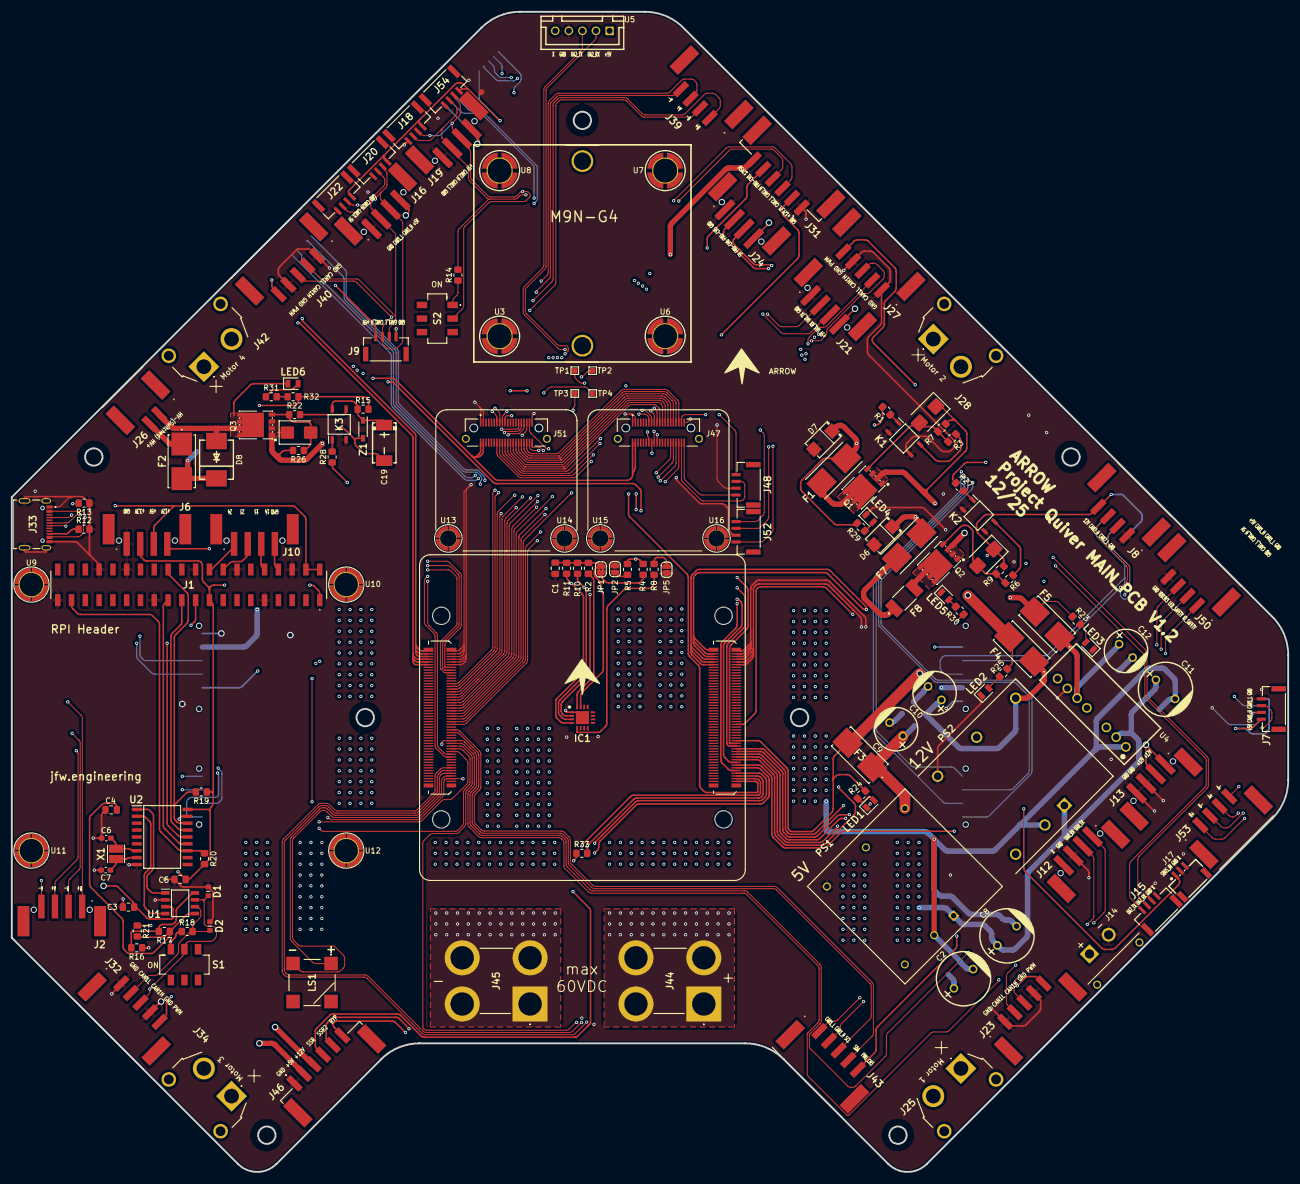
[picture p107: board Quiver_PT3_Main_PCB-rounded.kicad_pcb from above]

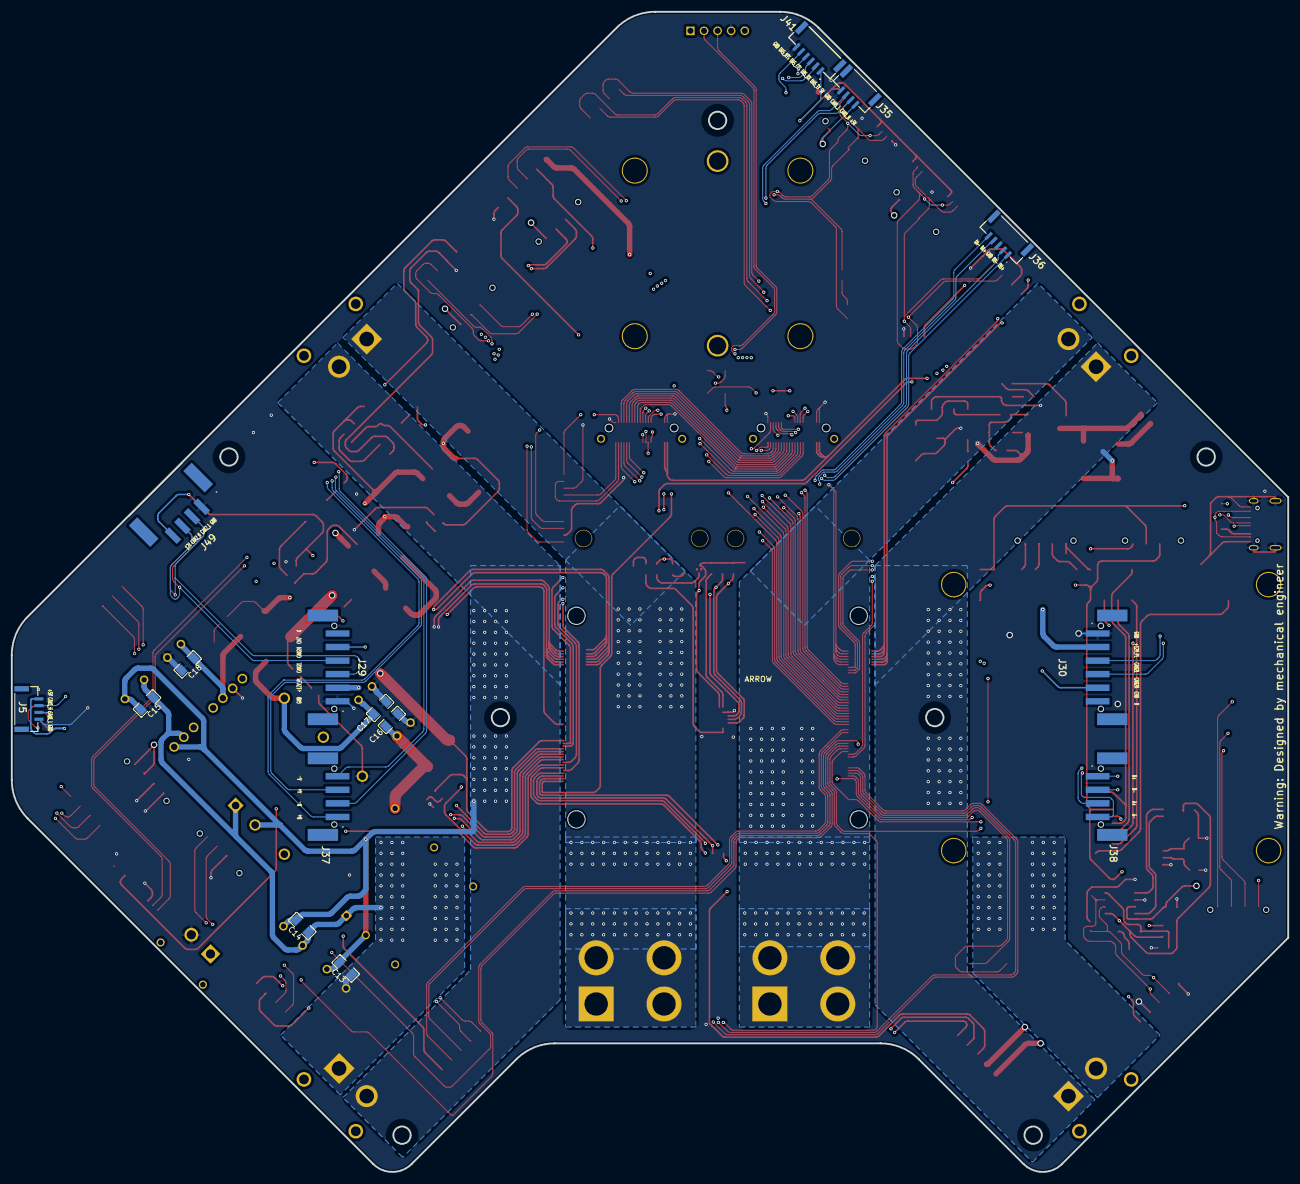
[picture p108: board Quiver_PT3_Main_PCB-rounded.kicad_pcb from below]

Board: 6 copper layers, 235.1 x 213.7 mm, 164 parts (15 on the bottom side), 146 nets.

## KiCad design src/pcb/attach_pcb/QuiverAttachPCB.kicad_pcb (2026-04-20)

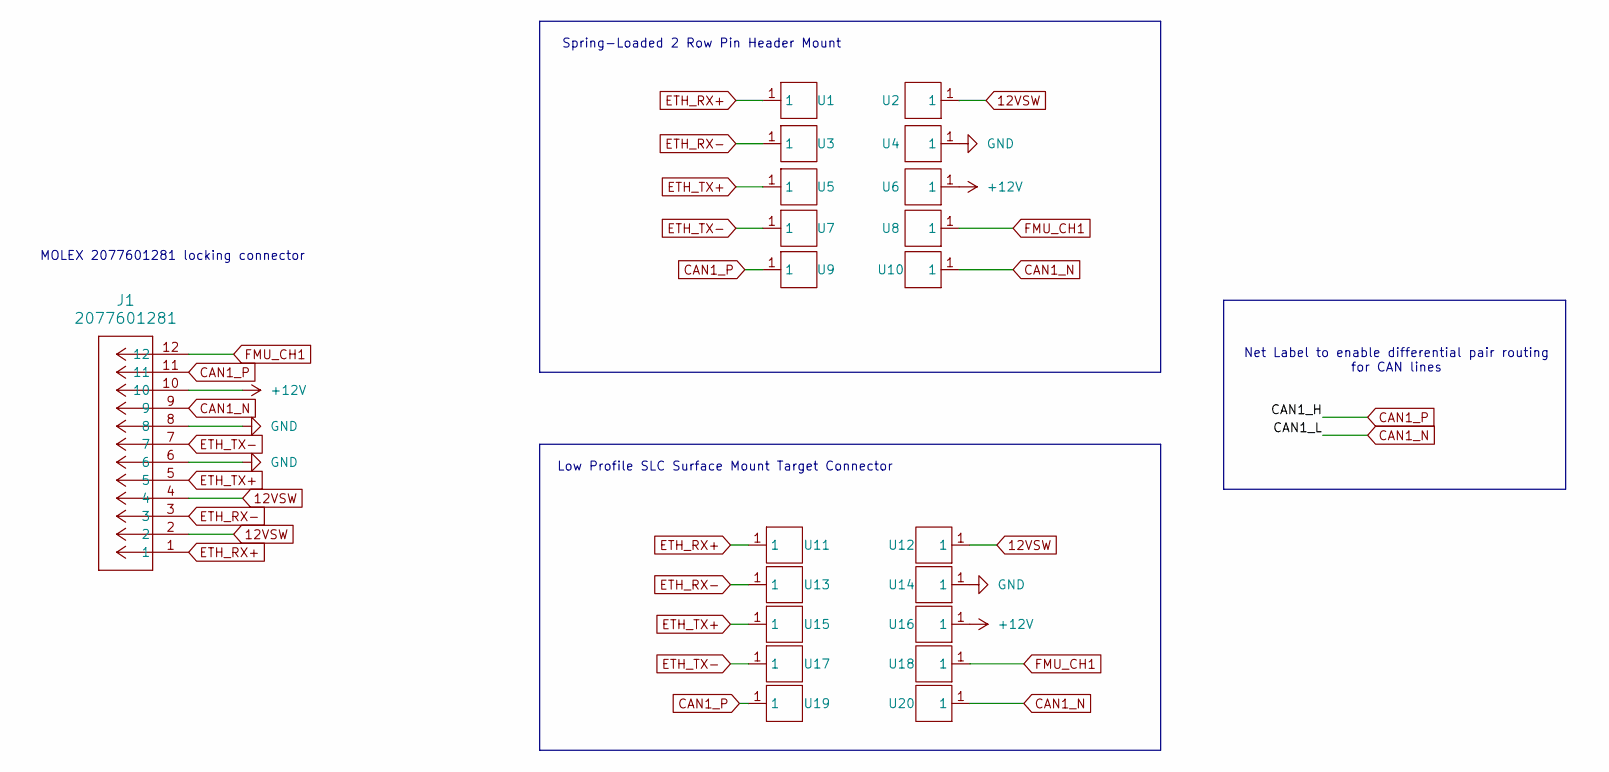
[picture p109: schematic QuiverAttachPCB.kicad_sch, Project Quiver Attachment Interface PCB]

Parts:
J1: 2077601281; CONN12_2077601281_MOL
U1, U2, U3, U4, U5, U6, U7, U8, U9, U10: C2826546-BWCD-L4.5W2.0H2.3; Manufacturer Part BWCD-L4.5W2.0H2.3; LCSC Part Name POGO PIN
U11, U12, U13, U14, U15, U16, U17, U18, U19, U20: C2826546-BWCD-L4.5W2.0H2.3_only_Pad_D2.0mm_1; Manufacturer Part BWCD-L4.5W2.0H2.3; LCSC Part Name POGO PIN

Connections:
12VSW: J1.2, J1.4, U2.1, U12.1
+12V: J1.10, U6.1, U16.1
CAN1_N: J1.9, U10.1, U20.1
CAN1_P: J1.11, U9.1, U19.1
ETH_RX+: J1.1, U1.1, U11.1
ETH_RX-: J1.3, U3.1, U13.1
ETH_TX+: J1.5, U5.1, U15.1
ETH_TX-: J1.7, U7.1, U17.1
FMU_CH1: J1.12, U8.1, U18.1
GND: J1.6, J1.8, U4.1, U14.1

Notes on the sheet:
MOLEX 2077601281 locking connector
Spring-Loaded 2 Row Pin Header Mount
Low Profile SLC Surface Mount Target Connector
Net Label to enable differential pair routing for CAN lines

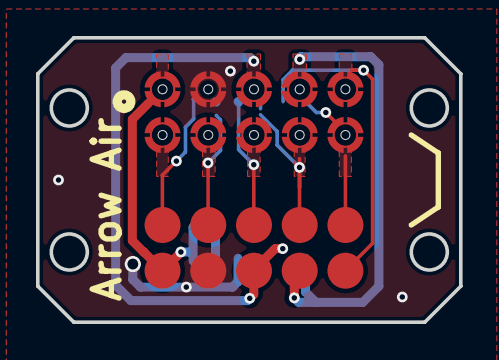
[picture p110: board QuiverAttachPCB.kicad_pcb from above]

Board: 2 copper layers, 23.5 x 15.8 mm, 21 parts (1 on the bottom side), 10 nets.

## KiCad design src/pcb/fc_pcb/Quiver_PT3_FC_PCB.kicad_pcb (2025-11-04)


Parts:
C1: 10uF; C_0805_2012Metric_Pad1.18x1.45mm_HandSolder
C2, C7, C8, C9, C10, C11, C12, C13, C14: 10uF, 10V, 0805; C_0805_2012Metric_Pad1.18x1.45mm_HandSolder
C3, C4, C5, C6: 47uF; C_0805_2012Metric_Pad1.18x1.45mm_HandSolder
D1, D2: SMDJ5.0CA; DIONM7959X262N; Mouser Part Number 576-SMDJ5.0CA
D3: DFLS240L-7; DFLS240L7; Mouser Part Number 621-DFLS240L-7
F1, F2, F3: NANOSMDC035F-2; NANOSMDC016F2; Mouser Part Number 650-NANOSMDC035F-2
FL1, FL2, FL3, FL4, FL5, FL6, FL7, FL8: NFM21PC104R1E3D; Mouser Part Number 81-NFM21PC104R1E3D
J1: AXK5S00347YG; AXK5S00347YG_AXK5S00347YG; MANUFACTURER_PART_NUMBER AXK5S00347YG
J2, J3: AXK5S00047YG; Mouser Part Number AXK5S00047YG
JP1: SolderJumper_2_Open; SolderJumper-2_P1.3mm_Open_RoundedPad1.0x1.5mm
LED1, LED2, LED3, LED4, LED5, LED6, LED7, LED8: APT2012LVBC_D; LEDC2012X85N; Mouser Part Number 604-APT2012LVBCD
R1, R2, R3, R4: 22R; R_0805_2012Metric_Pad1.20x1.40mm_HandSolder
R5, R6, R7, R8, R10, R12: 1K2; R_0805_2012Metric_Pad1.20x1.40mm_HandSolder
R9, R11: 330R; R_0805_2012Metric_Pad1.20x1.40mm_HandSolder

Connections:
/ I2C2_SDA_GPS2_MAG_LED: J1.23, J2.83
/BAT1_I: J1.36, J3.20
/BAT1_V: J1.34, J3.18
/BAT2_I: J1.32, J3.16
/BAT2_V: J1.30, J3.14
/BUZZER+: F2.2, J2.91
/BUZZER-: J1.88, J2.65, J2.93
/CAN1_H: J1.17, J2.49
/CAN1_L: J1.15, J2.47
/CAN2_H: J1.13, J2.55
/CAN2_L: J1.11, J2.53
/FMU_CH1: J1.65, J3.69
/FMU_CH2: J1.67, J3.71
/FMU_CH3: J1.69, J3.73
/FMU_CH4: J1.71, J3.75
/FMU_CH5: J1.73, J3.77
/FMU_CH6: J1.75, J3.79
/FMU_CH7: J1.77, J3.81
/FMU_CH8: J1.79, J3.83
/I2C1_SCL_GPS1_MAG_LED: J1.51, J2.75
/I2C1_SDA_GPS1_MAG_LED: J1.49, J2.73
/I2C2_SCL: J1.21, J2.61
/I2C2_SCL_GPS2_MAG_LED: J1.25, J2.85
/I2C2_SDA: J1.19, J2.59
/IO_CH1: J1.85, J3.85
/IO_CH2: J1.87, J3.87
/IO_CH3: J1.89, J3.89
/IO_CH4: J1.91, J3.91
/IO_CH5: J1.93, J3.93
/IO_CH6: J1.95, J3.95
/IO_CH7: J1.97, J3.97
/IO_CH8: J1.99, J3.99
/IO_PPM_INPUT: J1.82, R3.1
/IO_PPM_INPUT_AND_SBUS_INPUT: J3.55, R2.2, R3.2
/IO_RSSI_IN: J1.80, R4.1
/IO_RSSI_IN_AND_SBUS_OUT: J3.57, R1.2, R4.2
/IO_SAFETY_SWITCH_IN: J1.92, J2.71, J2.99
/IO_VDD_3V3: F1.2, J2.67, J2.95, R9.1
/N_IO_LED_SAFETY: J1.90, J2.69, J2.97
/SBUS_INPUT: J1.84, R2.1
/SBUS_OUT: J1.86, R1.1
/SPEKTRUM_DSM_IN: J1.94, J3.59
/UART5_CTS_TEL2: J1.33, J2.33
/UART5_RTS_TEL2: J1.31, J2.31
/UART5_RX_TEL2: J1.35, J2.35
/UART5_TX_TEL2: J1.37, J2.37
/UART7_CTS_TEL1: J1.41, J2.23
/UART7_RTS_TEL1: J1.39, J2.21
/UART7_RX_TEL1: J1.43, J2.25
/UART7_TX_TEL1: J1.45, J2.27
/UART8_RX_GPS2: J1.27, J2.87
/UART8_TX_GPS2: J1.29, J2.89
/USART1_RX_GPS1: J1.53, J2.77
/USART1_TX_GPS1: J1.55, J2.79
/USART2_RX_TEL3: J1.58, J2.41
/USART2_TX_TEL3: J1.76, J2.43
/USB_D+: J1.7, J2.17
/USB_D-: J1.5, J2.15
/VBUS: J1.3, J2.13
/VDD5V_BRICK1: C5.2, J1.16, J1.18, J1.20, J1.22, J1.24, J1.26, J2.2, J2.4, J2.6, J2.8, J2.10, J2.12, JP1.1 (A), R12.1
/VDD5V_BRICK2: C6.2, J1.2, J1.4, J1.6, J1.8, J1.10, J1.12, J3.2, J3.4, J3.6, J3.8, J3.10, J3.12, R10.1
/VDD_3V3_SPEKTRUM: C1.1, J1.96, J3.61, R11.1
/VDD_5V_CAN1: C7.1, FL1.3 (OUT), J2.45
/VDD_5V_CAN2: C13.1, FL7.3 (OUT), J2.51
/VDD_5V_GPS1: C8.1, FL2.3 (OUT), J2.63
/VDD_5V_GPS2: C11.1, FL5.3 (OUT), J2.81
/VDD_5V_HIPOWER: C4.2, D1.2, FL3.1 (IN), J1.62, J1.64, J1.66, R5.1
/VDD_5V_I2C: C14.1, FL8.3 (OUT), J2.57
/VDD_5V_PERIPH: C3.1, D2.2, D3.2 (A), F3.2, FL1.1 (IN), FL2.1 (IN), FL4.1 (IN), FL5.1 (IN), FL6.1 (IN), FL7.1 (IN), FL8.1 (IN), J1.68, J1.70, J1.72, R6.1
/VDD_5V_PPM_SBUS: C2.2, J1.74, J3.53, R7.1
/VDD_5V_TEL1: C9.1, FL3.3 (OUT), J2.19
/VDD_5V_TEL2: C10.1, FL4.3 (OUT), J2.29
/VDD_5V_TEL3: C12.1, FL6.3 (OUT), J2.39
/VDD_SERVO: J1.81, J3.63, J3.65, J3.67, R8.1
GND: C1.2, C2.1, C3.2, C4.1, C5.1, C6.1, C7.2, C8.2, C9.2, C10.2, C11.2, C12.2, C13.2, C14.2, D1.1, D2.1, FL1.2 (GND_1), FL1.4 (GND_2), FL2.2 (GND_1), FL2.4 (GND_2), FL3.2 (GND_1), FL3.4 (GND_2), FL4.2 (GND_1), FL4.4 (GND_2), FL5.2 (GND_1), FL5.4 (GND_2), FL6.2 (GND_1), FL6.4 (GND_2), FL7.2 (GND_1), FL7.4 (GND_2), FL8.2 (GND_1), FL8.4 (GND_2), J1.1, J1.9, J1.14, J1.28, J1.42, J1.47, J1.60, J1.78, J1.83, J1.100, J2.1, J2.3, J2.5, J2.7, J2.9, J2.11, J3.1, J3.3, J3.5, J3.7, J3.9, J3.11, LED1.1 (K), LED2.1 (K), LED3.1 (K), LED4.1 (K), LED5.1 (K), LED6.1 (K), LED7.1 (K), LED8.1 (K)
unnamed: D3.1 (K), F2.1
unnamed: F1.1, J1.98
unnamed: F3.1, JP1.2 (B)
unnamed: LED1.2 (A), R5.2
unnamed: LED2.2 (A), R6.2
unnamed: LED3.2 (A), R7.2
unnamed: LED4.2 (A), R8.2
unnamed: LED5.2 (A), R9.2
unnamed: LED6.2 (A), R10.2
unnamed: LED7.2 (A), R11.2
unnamed: LED8.2 (A), R12.2

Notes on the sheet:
3.0A Max
0.2A Max
0.3A Max
1.5A Max
Connector_MF_2
USB ESD Componets are placed on FMU Board No additional ESD protect is required here
Connector_MF_1
Note: 1.if DSM_IN and SBUS_IN share the same Conncetor PIN, PPM_IN use individual connector tie SPEKTRUM_DSM_IN and SBUS_INPUT nets together directly 2.if PPM_IN and SBUS_IN share the same Conncetor PIN, DSM_IN use individual connector tie PPM_IN and SBUS_INPUT nets together directly 3.RSSI_IN and 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



Board: 4 copper layers, 70.0 x 60.0 mm, 52 parts (24 on the bottom side), 86 nets.

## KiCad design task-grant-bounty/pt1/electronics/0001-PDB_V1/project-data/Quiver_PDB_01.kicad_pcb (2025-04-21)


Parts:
IC1: CPC1002NTR; SOP254P610X216-4N; Mouser Part Number 849-CPC1002NTR
J1: XT30PW-F; XT30PW-F_AMASS_XT30PW-F; PARTREV 1.2
J2, J7, J9, J11: 39512-1002; SHDRRA2W80P0X381_1X2_901X920X730P; Mouser Part Number 538-39512-1002
J3, J8: 39512-1004; SHDRRA4W80P0X381_1X4_1663X920X730P; Mouser Part Number 538-39512-1004
J4: 39512-1006; 395121006; Mouser Part Number 538-39512-1005
J5: 39512-1010; 395121010; Mouser Part Number 538-39512-1005
J6: 39512-1007; 395121007; Mouser Part Number 538-39512-1005
J10, J12: 7460408; Mouser Part Number 710-7460408
J13: FCPDB; PDB_2; Mouser Part Number 200-SSQ12001FD
J14, J15, J16, J17: XT60PW-M; XT60PW-M_AMASS_XT60PW-M; PARTREV V1.2
J18: 39512-1005_M1; 395121005; Mouser Part Number 538-39512-1005
J19: 39512-1005_M2; 395121005; Mouser Part Number 538-39512-1005
J20: 39512-1005_M3; 395121005; Mouser Part Number 538-39512-1005
J21: 39512-1005_M4; 395121005; Mouser Part Number 538-39512-1005
K1: CPC1114N; SOP254P610X218-4N; Mouser Part Number 849-CPC1114N
R1, R2: 1R; R_0805_2012Metric_Pad1.20x1.40mm_HandSolder
R3, R7: 12K; R_0805_2012Metric_Pad1.20x1.40mm_HandSolder
R4, R5, R6: 150R; PWR163S2550R0F; Mouser Part Number 652-PWR163S-25-50R0F
U1, U2: 178.6165.0002; 17861650002; Mouser Part Number 576-178.6165.0002
U3: PRE_F; 17861650002; Mouser Part Number 576-178.6165.0002

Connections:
+5V: J4.1, J4.2, J6.1, U2.1
+12V: IC1.4 (DC_+), J1.P, J6.5, J8.1, U1.1
/1/21_Vbat: J5.9, J13.11 (PDB_VBat1)
/12VSW: IC1.3 (DC_-), J6.7
/CAN_H: J4.6, J6.4, J7.2, J8.4, J18.2 (Grey_CANH), J19.2 (Grey_CANH), J20.2 (Grey_CANH), J21.2 (Grey_CANH)
/CAN_L: J4.5, J6.3, J7.1, J8.3, J18.3 (Green_CANL), J19.3 (Green_CANL), J20.3 (Green_CANL), J21.3 (Green_CANL)
/FC_IO_CH5: J5.5, R3.2
/FMU_CH1: J5.6, J6.6
/FMU_CH2: J5.7, R7.1
/PDB+: J10.1, J10.2, J10.3, J10.4, J10.5, J10.6, J10.7, J10.8, J10.9, J10.10, J10.11, J10.12, J13.9 (PDB+)
/PDB-: J11.2, J12.1, J12.2, J12.3, J12.4, J12.5, J12.6, J12.7, J12.8, J12.9, J12.10, J12.11, J12.12, J13.10 (PDB-)
/PDB_Curr: J5.8, J13.22 (Cur)
/PWM_M1: J5.1, J18.5 (White_PWM)
/PWM_M2: J5.2, J19.5 (White_PWM)
/PWM_M3: J5.3, J20.5 (White_PWM)
/PWM_M4: J5.4, J21.5 (White_PWM)
/SS_LED+: J2.1, R1.2
GND: IC1.2 (-_CONTROL), J1.N, J4.3, J4.4, J6.2, J8.2, J13.15 (PDB_GND), J13.19 (PDB_GND), J13.23 (PDB_GND), J13.24 (PDB_GND), J18.1 (Yellow_GND), J18.4 (Black_GND_PWM), J19.1 (Yellow_GND), J19.4 (Black_GND_PWM), J20.1 (Yellow_GND), J20.4 (Black_GND_PWM), J21.1 (Yellow_GND), J21.4 (Black_GND_PWM), K1.2 (-CONTROL)
unnamed: IC1.1 (+_CONTROL), R7.2
unnamed: J3.1 (LED+), R1.1
unnamed: J2.2, J3.4 (LED-)
unnamed: J3.2 (SW+), K1.4 (LOAD_2)
unnamed: J3.3 (SW-), R2.1
unnamed: J9.1, R4.2, R5.2, R6.2
unnamed: J11.1, U3.1
unnamed: J13.2 (M1+), J14.1 (+)
unnamed: J13.1 (M1-), J14.2 (-)
unnamed: J13.4 (M2+), J15.1 (+)
unnamed: J13.3 (M2-), J15.2 (-)
unnamed: J13.6 (M3+), J16.1 (+)
unnamed: J13.5 (M3-), J16.2 (-)
unnamed: J13.8 (M4+), J17.1 (+)
unnamed: J13.7 (M4-), J17.2 (-)
unnamed: J13.17 (PDB_5V), U2.2
unnamed: J13.25 (PDB_12V), U1.2
unnamed: K1.1 (+CONTROL), R3.1
unnamed: K1.3 (LOAD_1), R2.2
unnamed: R4.1, R5.1, R6.1, U3.2

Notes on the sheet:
HV- with external Fuse and Safety Switch
HV+
HV- through Resistor
FC connector +5V (Main) +5V (Backup) GND GND CANL CANH IO_CH1 (PWM 1) IO_CH2 (PWM 2) IO_CH3 (PWM 3) IO_CH4 (PWM 4) IO_CH5 (Safety Switch) FMU_CH1 (AUX 1 Payload) FMU_CH2 (AUX 2 Payload) ADC1_3V3 (Current sensor) ADC1_6V6 (voltage sensor)
PDB
12V switch for payload DC motor
Power supply 5V - 5A cont. / 6A burst (25W) 12V - 4A cont. /5A burst (48W) Current measurment up to 440A burst (3.3V) Voltage measurment 1/21 (max 2.857V output at 60V)
Radar altimeter connector +12V GND CANL CANH
Power supply to SIYI HM30 air unit
Power Input from Battery
Motor Connectors
Switch connector for precharge
Battery CAN connector CANL CANH
Additional outside connectors
LED connector
Safety switch connector
Safety switch; external LED
Note to other connections not on this PCB - FC and SIYI HM30 are directly connected on top of battery - Camera and Gimbal are directly connected to HM30 - FC and GPS/Compass are directly connected on top of battery
Connectors on this PCB: 1. SIYI HM30 power connector 2. FC connector (6+10 pin) 3. Payload connector 4. Battery CAN connector 5. Radar altimeter connector 6. Safety Switch LED connector 7. Safety Switch connector 8. Precharge/power switch connector 9. Motor 1 connectors (XT60+5 pin) 10. Motor 2 con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
Note regarding the precharge/power connector: A switch is connected to the precharge/power connector. When the switch is enabled the power system will be precharged and 12V and 5V will be distributed to all devices. The drone is powered on. During precharge state the main voltage will be to low to 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
Note to power consumption of Quiver - SiYI A8 /12V = avg. 5W and peak up to 12W - HM30 video transmitter /12V = 5W - Radar altimeter /12V or 5V = up to 2W - Pixhawk 6X /5V = up to 2.5W - Pixhawk 6X peripherals /5V = limited to 1.5A / 7.5W - Payload around 10W at 12V (intermitted activation) = ~22W 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
Payload connector +5V GND CANL CANH +12V FMU_CH1 (AUX 1 Payload) 12VSW (SW 12V DC motor)



Board: 2 copper layers, 240.0 x 120.0 mm, 33 parts (4 on the bottom side), 38 nets.

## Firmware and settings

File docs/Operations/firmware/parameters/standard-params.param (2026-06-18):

# Quiver Standard Parameters
# Base configuration for Quiver dev kit (Pixhawk 6C)
#
# Based on PT3 flight configuration (2025-11-13)
# Drone-specific calibration values removed — must be calibrated per airframe
#
# Ethernet/PPP: DISABLED by default — load params-ethernet.param to enable
# Obstacle avoidance: DISABLED by default — load params-object-avoidance.param to enable
#
# See the Firmware & Parameters docs page for full documentation
#
# ⚠️  After loading, calibrate per-drone:
#   - Compass (COMPASS_OFS_*, COMPASS_DIA_*, etc.)
#   - Accelerometer (INS_ACCOFFS_*, INS_ACCSCAL_*)
#   - RC (RC*_MIN, RC*_MAX, RC*_TRIM)
#   - Barometer (BARO*_GND_PRESS)

AHRS_EKF_TYPE,3
AHRS_GPS_GAIN,1
AHRS_GPS_MINSATS,6
AHRS_GPS_USE,1
AHRS_OPTIONS,0
AHRS_ORIENTATION,0
AHRS_RP_P,0.2
AHRS_YAW_P,0.2
ANGLE_MAX,3000
ARMING_ACCTHRESH,0.75
ARMING_CHECK,1
ARMING_MAGTHRESH,100
ARMING_NEED_LOC,0
ARMING_OPTIONS,0
ARMING_RUDDER,2
ATC_ACCEL_P_MAX,68443.15
ATC_ACCEL_R_MAX,60184.69
ATC_ACCEL_Y_MAX,9049
ATC_ANG_LIM_TC,1
ATC_ANG_PIT_P,10.68668
ATC_ANG_RLL_P,11.33392
ATC_ANG_YAW_P,3.538
ATC_ANGLE_BOOST,1
ATC_INPUT_TC,0.15
ATC_RAT_PIT_D,0.009356325
ATC_RAT_PIT_FLTD,10
ATC_RAT_PIT_FLTT,10
ATC_RAT_PIT_I,0.1453998
ATC_RAT_PIT_IMAX,0.5
ATC_RAT_PIT_P,0.1453998
ATC_RAT_PIT_SMAX,50
ATC_RAT_RLL_D,0.009198768
ATC_RAT_RLL_FLTD,10
ATC_RAT_RLL_FLTT,10
ATC_RAT_RLL_I,0.142759
ATC_RAT_RLL_IMAX,0.5
ATC_RAT_RLL_P,0.142759
ATC_RAT_RLL_SMAX,50
ATC_RAT_YAW_D,0.01000001
ATC_RAT_YAW_FLTD,10
ATC_RAT_YAW_FLTE,2
ATC_RAT_YAW_FLTT,10
ATC_RAT_YAW_I,0.16
ATC_RAT_YAW_IMAX,0.5
ATC_RAT_YAW_P,1.6
ATC_RAT_YAW_SMAX,50
ATC_RATE_FF_ENAB,1
ATC_RATE_Y_MAX,30
ATC_SLEW_YAW,6000
ATC_THR_MIX_MAN,0.1
ATC_THR_MIX_MAX,0.5
ATC_THR_MIX_MIN,0.1
AVOID_ENABLE,0
BATT_ARM_VOLT,47.5
BATT_CAPACITY,30000
BATT_CRT_VOLT,44.8
BATT_FS_CRT_ACT,1
BATT_FS_LOW_ACT,2
BATT_FS_VOLTSRC,1
BATT_MONITOR,9
BATT_OPTIONS,128
BATT2_LOW_VOLT,48
BATT2_MONITOR,9
BRD_OPTIONS,1
BRD_SAFETY_DEFLT,0
BRD_SAFETY_MASK,16368
BRD_SAFETYOPTION,3
BRD_VBUS_MIN,4.3
CAN_D1_PROTOCOL,1
CAN_D1_UC_ESC_BM,15
CAN_D1_UC_NODE,10
CAN_D1_UC_NTF_RT,20
CAN_D1_UC_OPTION,128
CAN_D1_UC_POOL,16384
CAN_D2_PROTOCOL,1
CAN_D2_PROTOCOL2,14
CAN_P1_BITRATE,1000000
CAN_P1_DRIVER,1
CAN_P2_BITRATE,500000
CAN_P2_DRIVER,2
DISARM_DELAY,10
EK3_ENABLE,1
EK3_ERR_THRESH,0.2
EK3_GPS_CHECK,31
EK3_IMU_MASK,3
EK3_MAG_CAL,3
EK3_PRIMARY,0
EK3_SRC_OPTIONS,1
EK3_SRC1_POSXY,3
EK3_SRC1_POSZ,1
EK3_SRC1_VELXY,3
EK3_SRC1_VELZ,3
EK3_SRC1_YAW,1
FENCE_ACTION,1
FENCE_ALT_MAX,30
FENCE_ALT_MIN,-10
FENCE_ENABLE,1
FENCE_MARGIN,5
FENCE_RADIUS,60
FENCE_TYPE,7
FRAME_CLASS,1
FRAME_TYPE,1
FS_CRASH_CHECK,1
FS_DR_ENABLE,2
FS_DR_TIMEOUT,30
FS_EKF_ACTION,1
FS_EKF_FILT,5
FS_EKF_THRESH,0.8
FS_GCS_ENABLE,1
FS_GCS_TIMEOUT,5
FS_OPTIONS,16
FS_THR_ENABLE,1
FS_THR_VALUE,975
FS_VIBE_ENABLE,1
GPS_AUTO_CONFIG,2
GPS_BLEND_MASK,5
GPS_HDOP_GOOD,160
GPS_MIN_ELEV,13
GPS_NAVFILTER,8
GPS_PRIMARY,0
GPS_SAVE_CFG,1
GPS1_GNSS_MODE,77
GPS1_RATE_MS,200
GPS1_TYPE,9
GPS2_GNSS_MODE,69
GPS2_RATE_MS,200
GPS2_TYPE,9
INS_ACCEL_FILTER,10
INS_ENABLE_MASK,127
INS_FAST_SAMPLE,3
INS_GYR_CAL,1
INS_GYRO_FILTER,20
INS_GYRO_RATE,1
INS_HNTCH_ATT,40
INS_HNTCH_BW,58
INS_HNTCH_ENABLE,1
INS_HNTCH_FM_RAT,1
INS_HNTCH_FREQ,116
INS_HNTCH_HMNCS,2
INS_HNTCH_MODE,1
INS_HNTCH_REF,1
INS_RAW_LOG_OPT,9
INS_STILL_THRESH,2.5
INS_TRIM_OPTION,1
INS_USE,1
INS_USE2,1
INS_USE3,0
LAND_ALT_LOW,500
LAND_REPOSITION,1
LAND_SPEED,30
LOG_BACKEND_TYPE,1
LOG_BITMASK,407550
LOG_FILE_BUFSIZE,200
LOG_FILE_DSRMROT,1
LOG_FILE_MB_FREE,500
LOG_MAX_FILES,500
LOIT_ACC_MAX,250
LOIT_BRK_ACCEL,220
LOIT_BRK_DELAY,0.4
LOIT_BRK_JERK,500
LOIT_OPTIONS,1
LOIT_SPEED,1250
MOT_BAT_VOLT_MAX,60.9
MOT_BAT_VOLT_MIN,46.2
MOT_HOVER_LEARN,2
MOT_PWM_MAX,1950
MOT_PWM_MIN,1050
MOT_PWM_TYPE,10
MOT_SAFE_TIME,1
MOT_SPIN_ARM,0.07
MOT_SPIN_MAX,0.95
MOT_SPIN_MIN,0.1
MOT_SPOOL_TIME,0.5
MOT_THST_EXPO,0.74
MOT_YAW_HEADROOM,200
NET_ENABLE,0
NTF_LED_BRIGHT,3
NTF_LED_LEN,1
NTF_LED_TYPES,123079
OA_TYPE,0
PILOT_ACCEL_Z,250
PILOT_SPEED_UP,250
PRX_FILT,0.25
PRX1_MIN,1
PRX1_TYPE,5
PRX1_YAW_CORR,180
RCMAP_PITCH,2
RCMAP_ROLL,1
RCMAP_THROTTLE,3
RCMAP_YAW,4
RNGFND1_GNDCLR,0.75
RNGFND1_MAX,90
RNGFND1_MIN,0.7
RNGFND1_ORIENT,25
RNGFND1_RECV_ID,1
RNGFND1_SCALING,3
RNGFND1_TYPE,39
RTL_ALT,1000
RTL_ALT_FINAL,0
RTL_ALT_TYPE,1
RTL_CONE_SLOPE,3
RTL_LOIT_TIME,5000
SCHED_LOOP_RATE,400
SERIAL0_BAUD,115
SERIAL0_PROTOCOL,2
SERIAL1_BAUD,57
SERIAL1_OPTIONS,0
SERIAL1_PROTOCOL,2
SERIAL2_BAUD,57
SERIAL2_OPTIONS,0
SERIAL2_PROTOCOL,2
SERIAL3_BAUD,1000
SERIAL3_OPTIONS,0
SERIAL3_PROTOCOL,-1
SERIAL4_BAUD,57
SERIAL4_OPTIONS,0
SERIAL4_PROTOCOL,2
SERIAL5_BAUD,1000
SERIAL5_OPTIONS,0
SERIAL5_PROTOCOL,11
SERVO_GPIO_MASK,65520
SERVO_RATE,50
SERVO1_FUNCTION,33
SERVO1_MAX,1950
SERVO1_MIN,1050
SERVO1_TRIM,1500
SERVO2_FUNCTION,34
SERVO2_MAX,1950
SERVO2_MIN,1050
SERVO2_TRIM,1500
SERVO3_FUNCTION,35
SERVO3_MAX,1950
SERVO3_MIN,1050
SERVO3_TRIM,1500
SERVO4_FUNCTION,36
SERVO4_MAX,1950
SERVO4_MIN,1050
SERVO4_TRIM,1500
TERRAIN_ENABLE,1
TERRAIN_SPACING,100
THR_DZ,100
WPNAV_ACCEL,100
WPNAV_ACCEL_Z,50
WPNAV_JERK,1
WPNAV_RADIUS,25
WPNAV_RFND_USE,1
WPNAV_SPEED,350
WPNAV_SPEED_DN,100
WPNAV_SPEED_UP,100

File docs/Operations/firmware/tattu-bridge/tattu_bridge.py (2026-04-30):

import can
import struct
import time
import sys
import logging
import dronecan
from dronecan.driver.socketcan import SocketCAN

logging.basicConfig(
    level=logging.INFO,
    format="%(asctime)s [%(levelname)s] %(message)s"
)
log = logging.getLogger("tattu_bridge")

# --- Configuration ---
CAN_INTERFACE   = 'can0'
TATTU_CAN_ID    = 0x01109216
MY_NODE_ID      = 110
TARGET_BITRATE  = 1000000

# Sanity bounds for a 14S Tattu pack — adjust if using a different pack
VOLTAGE_MIN_V   = 38.0   # 14S @ 2.7V/cell
VOLTAGE_MAX_V   = 60.0   # 14S @ 4.3V/cell
CURRENT_MAX_A   = 400.0  # absolute max, reject anything beyond this

# If SOC was above this threshold and we suddenly read 0%, treat as decode error
SOC_JUMP_THRESHOLD = 10   # % — won't ignore if last SOC was also low


class TattuBridge:
    def __init__(self):
        self.collecting = False
        self.frames = []
        self.last_frame_time = 0
        self.bus = None
        self.node = None

        # Last-known-good state — broadcast stale values rather than 0%
        self.last_voltage = None
        self.last_current = None
        self.last_temp    = None
        self.last_soc     = None
        self.last_good_ts = 0

    def connect(self):
        try:
            self.bus = can.interface.Bus(channel=CAN_INTERFACE, interface='socketcan')
            log.info(f"Listener connected on {CAN_INTERFACE}.")

            driver = SocketCAN(CAN_INTERFACE)
            self.node = dronecan.node.Node(driver, node_id=MY_NODE_ID)

            node_info = dronecan.uavcan.protocol.GetNodeInfo.Response()
            node_info.name = 'org.tattu.bridge'
            node_info.software_version.major = 1
            self.node.node_info = node_info
            self.node.mode   = dronecan.uavcan.protocol.NodeStatus().MODE_OPERATIONAL
            self.node.health = dronecan.uavcan.protocol.NodeStatus().HEALTH_OK

            log.info(f"DroneCAN node {MY_NODE_ID} started.")
        except Exception as e:
            log.error(f"Connection error: {e}")
            sys.exit(1)

    def decode_and_broadcast(self):
        """Reassemble 8 raw Tattu frames, validate, and broadcast via DroneCAN."""
        full_data = bytearray()

        # --- Frame length validation ---
        # Frame 0 needs at least 7 bytes (we read [2:7]).
        # Subsequent frames can be shorter (the final Tattu frame is legitimately 6 bytes).
        if len(self.frames[0]) < 7:
            log.warning(f"Frame 0 too short ({len(self.frames[0])} bytes), discarding sequence")
            return

        # --- Reassembly ---
        full_data.extend(self.frames[0][2:7])        # Frame 0: skip 2-byte CRC, take 5 bytes
        for i in range(1, 8):
            full_data.extend(self.frames[i][0:min(len(self.frames[i]), 7)])  # take up to 7 bytes

        if len(full_data) < 12:
            log.warning(f"Reassembled data too short ({len(full_data)} bytes), discarding")
            return

        # --- Parse ---
        def read_u16(idx): return struct.unpack_from('<H', full_data, idx)[0]
        def read_i16(idx): return struct.unpack_from('<h', full_data, idx)[0]

        idx = 0
        vendor = read_u16(idx); idx += 2
        model  = read_u16(idx); idx += 2
        volts  = read_u16(idx); idx += 2
        amps   = read_i16(idx); idx += 2
        temp   = read_i16(idx); idx += 2
        soc    = read_u16(idx); idx += 2

        voltage_v   = volts / 1000.0
        current_a   = amps / 100.0
        temp_kelvin = temp + 273.15

        # --- Sanity validation ---
        # Reject obviously bad decodes before they confuse the FC
        if not (VOLTAGE_MIN_V <= voltage_v <= VOLTAGE_MAX_V):
            log.warning(f"Voltage out of range: {voltage_v:.2f}V — bad decode, discarding")
            return

        if abs(current_a) > CURRENT_MAX_A:
            log.warning(f"Current out of range: {current_a:.1f}A — bad decode, discarding")
            return

        if not (0 <= soc <= 100):
            log.warning(f"SOC out of range: {soc}% — bad decode, discarding")
            return

        # BUG FIX: Reject sudden 0% drop if last known SOC was above threshold
        # This is the main cause of the spurious 0% readings.
        if soc == 0 and self.last_soc is not None and self.last_soc > SOC_JUMP_THRESHOLD:
            log.warning(
                f"SOC jumped from {self.last_soc}% to 0% — likely frame misalignment, "
                f"holding last value"
            )
            # Rebroadcast last known good instead
            soc        = self.last_soc
            voltage_v  = self.last_voltage
            current_a  = self.last_current
            temp_kelvin = self.last_temp

        # --- Store last known good ---
        self.last_voltage = voltage_v
        self.last_current = current_a
        self.last_temp    = temp_kelvin
        self.last_soc     = soc
        self.last_good_ts = time.time()

        # --- Build and broadcast DroneCAN BatteryInfo ---
        msg = dronecan.uavcan.equipment.power.BatteryInfo()
        msg.battery_id            = 0
        msg.voltage               = voltage_v
        msg.current               = current_a
        msg.temperature           = temp_kelvin
        msg.state_of_charge_pct   = soc
        msg.status_flags          = (
            dronecan.uavcan.equipment.power.BatteryInfo().STATUS_FLAG_IN_USE
        )
        msg.model_instance_id     = model

        self.node.broadcast(msg)
        log.debug(f"Broadcast: {voltage_v:.2f}V  {current_a:.1f}A  {soc}%  {temp_kelvin-273.15:.1f}°C")

        # Keep node alive
        self.node.health = dronecan.uavcan.protocol.NodeStatus().HEALTH_OK
        self.node.mode   = dronecan.uavcan.protocol.NodeStatus().MODE_OPERATIONAL

    def _process_tattu_frame(self, msg):
        """Handle one raw Tattu CAN frame."""
        now = time.time()

        # BUG FIX: Reset on timeout *before* start-frame check
        if self.collecting and (now - self.last_frame_time > 0.2):
            log.debug("Sequence timeout, resetting")
            self.collecting = False
            self.frames = []

        # Start-frame detection: last byte == 0x80
        # BUG FIX: Only treat as start if we're NOT mid-sequence,
        # or if we've already collected a full 8 (shouldn't happen, but guard anyway).
        # This prevents a mid-sequence frame that happens to end in 0x80 from
        # resetting an in-progress good sequence.
        if len(msg.data) > 0 and msg.data[-1] == 0x80:
            if self.collecting and 0 < len(self.frames) < 8:
                log.warning(
                    f"0x80 tail detected mid-sequence at frame {len(self.frames)}, "
                    f"restarting collection"
                )
            self.collecting = True
            self.frames = []

        if self.collecting:
            self.frames.append(bytes(msg.data))
            self.last_frame_time = now

            if len(self.frames) == 8:
                self.decode_and_broadcast()
                self.collecting = False

    def run(self):
        self.connect()
        log.info("Bridge running...")

        while True:
            try:
                # BUG FIX: Drain ALL pending Tattu frames before handing
                # control to DroneCAN spin. The original code processed only
                # one frame per loop iteration, causing frame drops when the
                # Tattu burst arrives faster than the loop runs.
                while True:
                    raw = self.bus.recv(timeout=0)  # non-blocking
                    if raw is None:
                        break
                    if raw.arbitration_id == TATTU_CAN_ID:
                        self._process_tattu_frame(raw)

                # DroneCAN housekeeping (heartbeats, service requests)
                self.node.spin(0.005)

            except KeyboardInterrupt:
                log.info("Stopping.")
                break
            except Exception as e:
                log.warning(f"Loop error: {e}")
                time.sleep(0.1)


if __name__ == "__main__":
    bridge = TattuBridge()
    bridge.run()

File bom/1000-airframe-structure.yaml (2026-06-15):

category: "1000"
name: Airframe Structure
items:
  - id: "1111"
    name: Upper Plate
    qty: 1
    sourcing: laser-cut
    material: Aluminum
    spec: 1 mm sheet
    design_ref: src/quiver/airframe_structure/plates/steps/1111_upper_plate.step
    unit_cost_usd: 26.00
    suppliers:
      - name: RapidDirect
        url: https://www.rapiddirect.com/
        note: reference service; any shop meeting the spec is acceptable
  - id: "1112"
    name: Middle Plate
    qty: 1
    sourcing: laser-cut
    material: Aluminum
    spec: 1 mm sheet
    design_ref: src/quiver/airframe_structure/plates/steps/1112_middle_plate.step
    unit_cost_usd: 26.00
    suppliers:
      - name: RapidDirect
        url: https://www.rapiddirect.com/
  - id: "1113"
    name: Lower Plate
    qty: 1
    sourcing: laser-cut
    material: Aluminum
    spec: 1 mm sheet
    design_ref: src/quiver/airframe_structure/plates/steps/1113_lower_plate.step
    unit_cost_usd: 47.00
    suppliers:
      - name: RapidDirect
        url: https://www.rapiddirect.com/
  - id: "1211"
    name: Cockpit Support Beam, CW Long
    qty: 1
    sourcing: laser-cut
    material: Aluminum
    spec: 40x40x2 mm box section
    design_ref: src/quiver/airframe_structure/beams/steps/1211_cw_long.step
    unit_cost_usd: 43.00
    suppliers:
      - name: RapidDirect
        url: https://www.rapiddirect.com/
  - id: "1212"
    name: Cockpit Support Beam, CCW Back
    qty: 2
    sourcing: laser-cut
    material: Aluminum
    spec: 40x40x2 mm box section
    design_ref: src/quiver/airframe_structure/beams/steps/1212_ccw_back.step
    unit_cost_usd: 27.00
    suppliers:
      - name: RapidDirect
        url: https://www.rapiddirect.com/
  - id: "1221"
    name: Battery Wall
    qty: 2
    sourcing: laser-cut
    material: Aluminum
    design_ref: src/quiver/airframe_structure/beams/steps/1221_battery_wall.step
    unit_cost_usd: 49.00
    suppliers:
      - name: RapidDirect
        url: https://www.rapiddirect.com/
  - id: "1310"
    name: Landing Gear Vertical Tube
    qty: 4
    sourcing: cut-to-length
    material: Carbon fiber 3K
    spec: 30x28 mm tube; see landing_gear assembly for cut length
    design_ref: src/quiver/airframe_structure/landing_gear/assembly.py
    unit_cost_usd: 45.00
    purchase:
      qty: 2
      note: 30x28x1000 mm stock, any color; each tube yields two legs
    suppliers:
      - name: RJXHobby
        url: https://www.rjxhobby.com/carbon-fiber/carbon-fiber-tube/rjx-1pcs-colored-3k-carbon-fiber-tube-1000mm-od-21-30mm
  - id: "1320"
    name: Landing Gear Horizontal Tube
    qty: 2
    sourcing: cut-to-length
    material: Carbon fiber 3K
    spec: 30x28 mm tube; see landing_gear assembly for cut length
    design_ref: src/quiver/airframe_structure/landing_gear/assembly.py
    unit_cost_usd: 45.00
    purchase:
      qty: 1
      note: 30x28x1000 mm stock, any color; one tube yields both skids
    suppliers:
      - name: RJXHobby
        url: https://www.rjxhobby.com/carbon-fiber/carbon-fiber-tube/rjx-1pcs-colored-3k-carbon-fiber-tube-1000mm-od-21-30mm
  - id: "1330"
    name: Landing Gear Main Adapter
    qty: 4
    sourcing: cots
    spec: 30 mm tube quick-release tilt seat
    design_ref: src/quiver/airframe_structure/landing_gear/steps/vendor/1330_main_adapter.step
    unit_cost_usd: 30.00
    suppliers:
      - name: RJXHobby
        url: https://www.rjxhobby.com/rjx-1pcs-20mm-quick-release-tripod-aluminum-tilt-fixed-seat-landing-gear-connector-1
  - id: "1340"
    name: Landing Gear Tube Joint
    qty: 4
    sourcing: cots
    spec: 30 mm
    design_ref: src/quiver/airframe_structure/landing_gear/steps/1340_tube_joint.step
    unit_cost_usd: 13.99
    suppliers:
      - name: INNLOI
        url: https://www.innloi.com/productinfo/448455.html
  - id: "1350"
    name: Landing Gear Foam Wrap
    qty: 4
    sourcing: cots
    material: EPP foam
    design_ref: src/quiver/airframe_structure/landing_gear/assembly.py
    unit_cost_usd: 14.00
    purchase:
      qty: 1
      note: one pack wraps all four lower tubes
    suppliers:
      - name: Amazon
        url: https://a.co/d/ggzWXc4
  - id: "1411"
    name: Foldable Motor Arm Connector
    qty: 4
    sourcing: cots
    spec: 30 mm tube option
    design_ref: src/quiver/airframe_structure/motor_arm/steps/vendor/1411_arm_connector.step
    unit_cost_usd: 25.00
    suppliers:
      - name: Alibaba
        url: https://www.alibaba.com/product-detail/30-40mm-Folding-arm-tube-Drone_1600762096177.html
  - id: "1412"
    name: Motor Arm Tube
    qty: 4
    sourcing: cut-to-length
    material: Carbon fiber 3K
    spec: 30x28 mm tube, cut to 360 mm
    design_ref: src/quiver/airframe_structure/motor_arm/assembly.py
    unit_cost_usd: 45.00
    purchase:
      qty: 2
      note: 30x28x1000 mm stock, any color; each tube yields two arms
    suppliers:
      - name: RJXHobby
        url: https://www.rjxhobby.com/carbon-fiber/carbon-fiber-tube/rjx-1pcs-colored-3k-carbon-fiber-tube-1000mm-od-21-30mm

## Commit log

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2025-03-10 Remove board specific STAT parameters
    We don't need to track these here since they are unique to each individual flight controller
    [parameters.param]
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2025-05-28 fixed broken link in PT1-Engineering-Report.md
    fixed broken link for attachment interface
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2025-06-11 Fix power limit in AB-1 and P-2
2025-06-11 Fix power limit at AB-1. Fix standard description in AB-4.
2025-06-11 Fix power limit in AB-1. Fix standard description in AB-3.
2025-06-11 Fix power limit at AB-1.
2025-06-11 Update 002-General_Aerial_LiDAR_Scanning_Device_comprehensive_requirement).md
    Fix power limit in AB-1. Fix standard description in AB-6.
2025-06-11 Fix power limit in AB-1.
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2025-08-14 Fix: 1.2mm correct board thickness
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2025-09-08 Object avoidance sensor selection information note
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2026-01-18 Refactor Engineering Reports for Docusaurus compatibility
    - Move PT1 and PT2 reports to Engineering-Reports root (remove subfolders)
    - Add Docusaurus frontmatter (title, sidebar_position, description)
    - Fix MDX compatibility issues:
    - Convert <br> to <br/>
    - Remove nested <details> tags
    - Fix spacing after </summary> for proper markdown rendering
    - Clean up PT1 header formatting
    - Simplify Mouser BOM table for better display
    - Add _category_.json for sidebar configuration
    Note: PT2 images need re-uploading (holocron.so links are broken)
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2026-01-24 Move flight-test to repo root and fix CI checks
    - Move flight-test folder from docs/ to repository root
    - Add README explaining it's an archive of early flight tests
    - Add .editorconfig-checker.json to exclude binary/generated files
    - Update .cspell.config.yaml to exclude KiCAD and binary files
    - Add project-specific words to spell checker dictionary
    - Fix formatting issues in JSON files and markdown
    [parameters.param]
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2026-01-25 Move PT3 report to match PT1/PT2 structure and fix typos
    - Move PT3-Engineering-Report.md to docs/Engineering-Reports/
    - Update image paths from images/ to PT3/images/
    - Fix typos: "heat sync" -> "heat sink", "Pix 32 V6" -> "Pix32 V6"
    - Fix grammar: "a various form factors that integrates"
    - Remove double spaces and extra blank lines
    - Add missing period
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2026-02-02 Restructure CAD project to match BOM naming convention
    Replace the flat 6-subassembly layout with a two-level hierarchy
    matching the BOM categories (1000-5000) and subcategories (XX00).
    Folder names use descriptive names; BOM numbers appear in STEP file
    names and module docstrings for traceability.
    - airframe_structure/ (1000): plates, beams, landing_gear, motor_arm
    - supporting_structure/ (2000): attachment_interface, battery_slider,
    equipment_mount, cockpit_enclosure
    - equipment/ (3000): propulsion, peripheral, pcb, battery
    - harness/ (4000): placeholder for wiring harness
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2026-02-09 Add STEP parts and position plates/beams assemblies
    - Fix setuptools build backend (setuptools.build_meta)
    - Add VS Code launch config for viewer and export
    - Add STEP files for all subassemblies
    - Add assembly labels for OCP CAD Viewer tree
    - Position plates and beams to match Fusion 360 reference:
    - Plates: upper (Z=20), middle (Z=-21), lower (Z=-125)
    - Cockpit beams: X pattern at 45 deg between upper/mid plates
    - Battery walls: left/right sides between mid and lower plates
    - Ignore root-level STEP reference exports in .gitignore
    [1111_upper_plate.step, 1112_middle_plate.step, 1113_lower_plate.step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]
2026-02-09 Add motor arm assembly with generated carbon-fiber tubes
    - Position 4x foldable connectors at plate corners (45-deg diagonals)
    - Generate 30mm OD, 2mm wall carbon-fiber arm tubes in build123d
    - Move arm connector STEP to vendor/ directory
    - Improve code readability across plates, beams, and motor arm:
    - Fix axis labels in beams diagram for consistency
    - Add comments explaining battery wall rotation differences
    - Clarify plate Z position constants
    - Remove unused tuple labels from arm positions
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2026-02-09 Add attachment interface assembly and fix STEP import transforms
    Position the three quick-release interface plates (right, left, bottom)
    and their spacers to match the Fusion 360 reference. The plate STEP was
    re-exported to include only the drone-side mechanism (Fixed_Top + pins +
    springs), removing the payload-side Replaceable_Base.
    Fix a critical rendering bug where STEP files with internal placement
    transforms on sub-parts rendered in wrong locations in OCP CAD Viewer.
    Added _flatten() using BRepBuilderAPI_Copy to bake nested transforms
    into vertex data before applying assembly rotations/moves.
    [2112_attach_plate.step]
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2026-02-09 Add equipment mount assembly with positioned parts
    Position all 7 equipment mount parts (PCB mounts, altitude sensor,
    GNSS base/clamp, PPP/beacon mount) with Z offset corrections for
    parts whose Fusion export offset differs from the reference.
    [2341_ppp_beacon_mount.step]
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2026-02-09 Add propulsion and peripheral assemblies with vendor STEP files
    Propulsion (BOM 3100): 4 motor+propeller sets positioned at arm tips
    with CW/CCW rotation patterns. Peripheral (BOM 3200): 11 sensor and
    antenna parts with rotation and CoM-based positioning from Fusion
    reference. Add extract_solids flattening mode in common.py for vendor
    STEP files with deeply nested compound hierarchies (e.g. GNSS receiver)
    that crash the OCP CAD Viewer tessellator.
2026-02-10 Add PCB and battery assemblies, fix viewer for large assemblies
    PCB (BOM 3300): Main PCB, BC PCB with dZ offset, and 3 attachment
    interface PCBs rotated per position. Battery (BOM 3400): single
    battery pack, no transform needed. Add extract_solids with
    min_solid_volume filtering in common.py to handle large PCB STEP files
    with hundreds of tiny SMD solids. Use coarser tessellation
    (deviation=0.5) in --show to keep the full assembly renderable.
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2026-02-10 Fix CI spelling and editorconfig checks
    Add project-specific words to .cspell dictionary and re-indent ASCII
    diagrams in assembly docstrings to use multiples of 4 spaces.
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2026-02-13 Add technical terms to cspell word list
    Words from Dev-Kit-Guides docs:
    - Aviation terms: VLOS, EASA, PDRA, LAANC, Geoportal, dipul, UFLY
    - SDK/Python terms: aiohttp, asyncio, dronecan, mavsdk, socketio, etc.
    - Linux/tools: journalctl, timedatectl, nslookup, mavproxy, netplan
    - Hardware: Adafruit, Nailboard
    - Misc: Failsafes, backpressure, SITL, xxmm
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2026-02-13 Update assembly guide with new components and details
    Added new screws, inserts, and a vibration mount to the assembly guide. Updated descriptions for clarity.
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2026-02-14 Update assembly steps and correct terminology
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2026-02-19 Fix spelling errors in task-grant-bounty docs
    Typo fixes:
    - Ethernet-Setup-Guide.md: addressses→addresses, adpater→adapter,
    automaticly→automatically, passwort→password
    - Front-PCB-Update.md: notablely→notably
    - Main-PCB-Update.md: Dedicatd→Dedicated
    - readme.md: Sturcture→Structure
    Added to word list: kbit, Mbit, GWADDR, IPADDR, Imager, autoremove, Ruthex, autotest
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2026-02-27 hw: Update GNSS mount to F9P variant (2331-GNSSMount_F9P v6 v1)
    Replace 2331_gnss_mount_base.step with updated F9P GNSS mount design.
    Exported from Inventor by Alperen, 2026-02-27.
    [2331_gnss_mount_base.step]
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2026-03-11 Update vibration mount and weight reduction information noteand
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2026-03-26 UPDATE pilot-handbook for "gimbal camera" + multiple "failure" + "contact" parts
2026-03-30 Update Pilot-Handbook.md
    Safety-Critical Gaps
    2. §3.3 Step 9 / §2.5.3 — Replace "adequate GPS fix" with a specific threshold.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
2026-04-15 Fix file extension mismatches in structural assembly guide
    Correct CAD links for 2XXX parts (.step -> .stl), step18_2/3/4/5 images (.jpeg -> .png), and 3324 4mm variant (3324.step -> 3324_1.step) so links match the actual files on disk.
2026-04-15 fix: use YAML array for tags in PCB assembly guide front matter
    Docusaurus requires tags to be a YAML array. These three files had
    tags as a bare string, causing the website build to fail.
2026-04-15 fix: replace broken image refs with TODO placeholders
    Images differ between PT3 and devkit, so using PT3 assets would be
    incorrect. Replaced with TODO notes until correct devkit images are available.
    Affected files:
    - structural-assembly.md: step13_1.png (busbar installation)
    - Manufacturing-Guide.md: 1221_1222.png and .step (battery wall)
2026-04-15 fix: correct all broken image and model paths in devkit docs
    Manufacturing-Guide.md: ~85 image refs used assets/images/ instead of
    ./Assembly-Guides/assets/images/structural/. Same for ~20 model refs.
    Also fixed step18_2-5 using .jpeg extension when files are .png.
    structural-assembly.md: step11_3-5 are genuinely missing — replaced
    with TODO comments.
    Both files: step13_1 remains as TODO (from prior fix).
    Verified: zero broken local image refs remaining across all docs.
2026-04-16 Add transport case foam insert information note
    Add Pelican 1640 custom foam insert documentation for the Quiver
    transport case bounty (Issue #192). Includes:
    - Information note with foam layer design, CAD links, manufacturing
    process, material list, and assembly instructions
    - 5 reference images (2 CAD renders, 3 build photos)
    - 2 DXF laser cutting layouts (Foam_1.dxf, Foam_2.dxf)
    Files organized under task-grant-bounty/Dev-Kit/ with new
    images/transport-case/ and data/ subdirectories.
    [Foam_1.dxf, Foam_2.dxf]
2026-04-16 Update structural assembly guide (BOM, HTML images, step shift)
    - Move tool list into BOM as Table 3 (Tools and Consumables) with McMaster refs for Loctite 222/242 and Würth Super RTV Silicone
    - Remove silicone adhesive between aluminum layer references and delete the four contact images (step1_3, step2_3, step4_3, step5_3)
    - Convert all image references to HTML img tags with width="600"
    - Shift Steps 19-21 to Steps 20-22 and rename associated assets to free the Step 19 slot
    - Populate Step 20 (Main Enclosure and Top Cap) parts list including consumables
    - Replace step16_1.png with upscaled version
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2026-04-17 Fix landing legs wording, remove bounty proposal section
    - Change 'minus detached landing legs' to 'with detached landing legs'
    - Remove Bounty or Grant Proposal Document section (no formal bounty
    proposal exists for this work)
2026-04-17 Revise structural assembly guide: fastener corrections, consumables, wording
    - Fix BOM quantities to match step usage across all fasteners
    - Remove unused Screw 3 (old) and Insert 3 (old), renumber Screw 18 and Insert 5 into the freed slots
    - Add consumables (Loctite, Würth RTV, double-sided tape, silicone foam seal strip) to Parts needed in all steps that use them
    - Normalize parenthetical fastener descriptions to match BOM exactly
    - Fix grammar: "shown to" -> "shown in", "connecters" -> "connectors", consistent "DO NOT use" casing
    - Fix Step 14 fastener type (Screw 5 vs Screw 7) and Step 13 missing Loctite in parts list
    - Fix BOM sourcing contradictions for 134X and 243X
    - Add landing gea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
    [2311.stl, 2312.stl, 2313.stl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]
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2026-04-18 fix: sync Manufacturing-Guide with structural-assembly v1.1 changes
    Alperen's PR #195 reorganized structural-assembly.md, removing the
    'Adhesive Area' column and consolidating steps to 2 images each.
    Manufacturing-Guide.md still had the old 3-column tables referencing
    deleted images (step1_3, step2_3, step4_3, step5_3, step9_6).
    Updated tables to match the current 2-column structure rather than
    leaving TODO placeholders.
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2026-05-11 Reorder Screw 3 to correct numerical position in fasteners BOM
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2026-06-10 test: add CAD assembly smoke tests and pinned constraints
    The assembly was previously never executed in CI; a missing or broken
    STEP file silently produced a partial model. Tests pin the subassembly
    tree, bounding box, solid count, and code<->file STEP references.
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2026-06-10 refactor: dedupe center-of-mass placement into common.place_at
    Removes the unused bulk STEP loaders, warns instead of silently
    skipping missing STEP files, and notes the Fusion 360 provenance of
    position constants in each assembly module. Geometry verified
    unchanged by the smoke tests (bbox + solid counts).
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2026-06-10 docs: add contributor scaffolding and attachment design template
    Adds a repo-local CONTRIBUTING quickstart (shallow clone, CAD setup,
    test workflow), SECURITY policy for safety-critical defects, code of
    conduct, issue/PR templates, and a parametric example attachment in
    src/quiver/attachments/designs/ that CI now builds.
2026-06-10 fix: repair CI checks exposed by first cad_checks run
    The terraform sync (d2a354e, pushed with a skip-ci marker) had
    clobbered the cspell binary-file ignores from #219, so the spelling
    check was silently broken on main; reverted in the previous commit.
    This commit restores the dropped case-variant word-list entries, adds
    constraint package names, excludes relocated KiCad auxiliary files
    from the editorconfig checker, removes a KiCad autosave temp file, and
    fixes two continuation-indent violations.
2026-06-10 fix: ignore constraints lockfile in cspell, scope SECURITY.md to vulnerabilities
    The sanity-check docker image carries an older cspell without the
    software-terms dictionary, so package names in the lockfile fail there
    while passing locally; lockfiles should not be spell-checked at all.
    SECURITY.md now covers only remotely exploitable issues per review
    feedback - mechanical/CAD defects go to the public tracker.
2026-06-11 fix: restore repo-specific cspell ignore paths
    The June 7 Terraform repository sync overwrote this file with the
    shared org template, dropping the KiCad/hardware binary ignore paths
    added in #219. Terraform no longer manages this file's content
    (Arrow-air/tf-github#162), so this restore will stick.
2026-06-12 feat: structured, validated bill of materials
    The BOM is now version-controlled master data in bom/*.yaml — one file
    per BOM category plus fasteners and consumables, 143 items with
    suppliers, costs, and design references. python -m quiver.bom
    validates the schema and renders the committed docs page and
    procurement CSV; CI fails when they are stale. Tests cross-check every
    CAD part id and instance count against the BOM using the existing
    session assembly fixture.
    load_step now normalizes part labels to the BOM-numbered STEP filename
    (embedded Fusion names disagreed with the canonical numbering), which
    also makes the 3D viewer hover names match the BOM; web GLBs
    regenerated accordingly.
    Da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
    [quiver-bom.csv]
2026-06-12 style: fix continuation indents in bom CLI
2026-06-12 fix: resolve GNSS and telemetry-antenna TBCs
    Per maintainer confirmation: the Wren Mini is retired and either the
    Here4 or the Holybro H-RTK F9P is acceptable as primary GNSS (both now
    listed as approved suppliers); the front/rear telemetry antennas are
    supplied with the SIYI HM30 Standard Combo. The heatsink TBC remains
    pending a Fusion drawing export.
    [quiver-bom.csv]
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2026-06-12 fix: resolve remote control TBC as builder's choice
    No transmitter is formally specified for Quiver; the RadioMaster Boxer
    is listed as the reference example per the maintainer.
    [quiver-bom.csv]
2026-06-12 feat: add BC PCB heatsink design file, resolve its TBC
    First fabrication file in src/manufacturing/ per its BOM-prefix
    convention. Measured envelope is 116x16x5 mm; the part has been
    called the '4 mm' heatsink since the original BOM sheet, so the name
    is kept and the spec records the measured envelope.
    [3324_bc_pcb_heatsink.step, quiver-bom.csv]
2026-06-12 fix: heatsink is the 5 mm variant
    Both 4 mm and 5 mm variants were prototyped; the 5 mm one is the
    keeper per the maintainer. Name and spec updated to match the
    committed STEP.
    [quiver-bom.csv]
2026-06-12 fix: transport case is the Nanuk 976
    Links the existing Dev-Kit foam cut profiles as the case insert
    reference.
    [quiver-bom.csv]
2026-06-12 feat: declare BOM revision A
    The JST GH cable assortment gets its reference kit (Amazon, AliExpress
    equivalents acceptable), closing the last TBC. All 143 items now have
    confirmed identities, suppliers or builder's-choice notes, and design
    references; meta.yaml flips from draft to final.
    [quiver-bom.csv]
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2026-06-17 `standard-params.param`: move Lidar360 from SERIAL3 to SERIAL5 (`SERIAL3_PROTOCOL` 11 -> -1, add `SERIAL5_PROTOCOL=11`, `SERIAL5_BAUD=1000`, `SERIAL5_OPTIONS=0`). - `firmware/index.md`: "Connect to S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
    [params-object-avoidance.param, standard-params.param]
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2026-09-19 Correct sensor mesh diagnosis using native and solid volumes
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2026-09-25 feat(pcb): replace PT3 Main PCB sources with Dev-Kit V1.2, battery PCB with V1.3
    The Main PCB KiCad project on main was the PT3 first revision (September
    2025). The Dev-Kit aircraft flies Main PCB V1.2 (January 2026), which moved
    the payload and HV switching to MOSFETs driven by CPC1019N SSRs, added the
    backup 5 V supply (U4), the dedicated lidar connector (U5), JST-GH
    connectors, and the Raspberry Pi standoffs. Designators and control channels
    differ between the two revisions, so documentation citing the old files was
    wrong for the flying board.
    main_pcb: V1.2 rounded project (board, schematic, four sub sheets, library
    tables, EasyEDA library, production BOM, positions, IPC netlist and the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
    [CAN circuit.kicad_sch, ETHERNET.kicad_sch, Front_PCB.kicad_pcb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]
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2026-10-01 docs: Dev-Kit Engineering Report corrections ER1 to ER10
    Sensor loadout as configured (RPLidar S2 S2M1-R2, NanoRadar NRA15 and
    MR82 on CAN2 with distinct CAN IDs), lidar dropout resolved 2026-06-17,
    current flight image PR #230 git 20622a39, Remote ID module firmware
    (db200, node 123, web OTA plus power cycle), packs are 14S LiHV with the
    Tattu 4.0 BMS on battery instance 2, SSR backup trace named per the
    V1.2 schematic, GNSS interference from the Ethernet switches (testing
    in progress), 100BASE-TX links, network table with the current
    addresses and the PPP addressing note, weight table restated.
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2026-10-16 Place equipment at Fusion v148 occurrences; replace 2341 with the board
    Review follow-up for #266 (Erick, October 1):
    - 3260 push button: move to the left front face (Fusion 3231); the old
    position cut into the updated 2411 wall.
    - 3280 HM30 air unit: rotate 180 deg about Z (Fusion 3223 occurrence).
    - 3290 MR82 radar: rotate 180 deg and remove the 5 deg tilt baked into
    its component-frame STEP (Fusion 3212 occurrence).
    Same check across every peripheral and the main PCB:
    - 3210 LiDAR +4 mm into the new top-cap slot; 3220 radar altimeter
    +5 mm X; 3201 PPP adapter rotZ -45 (was +45) and 3201/3202 moved onto
    the mounting board; 3310 main PCB -7.40 mm onto the 2311 adapter.
    2341: the p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
2026-10-16 Fix propeller handedness, tube walls, and right attach spacer vs Fusion v148
    - Propulsion: diagonal CW/CCW pairs (CW on FR+BL, CCW on FL+BR) to match
    Fusion and give a valid Quad X yaw balance. The repo had same-side pairs
    (CW FR+BR, CCW FL+BL), leaving a net yaw torque. Swap 3112/3122 at the
    rear corners; placement rotations unchanged.
    - Landing gear + motor arm: carbon tube wall 2mm -> 1mm (30x28 tube per BOM
    and Manufacturing Guide; Fusion solid volumes match 1mm, not 2mm).
    - Attachment interface: right spacer 2111 was a 180deg Z flip, ~3.3mm off.
    Mirror about Y (Fusion occurrence diag -1,+1,-1) and pin CoM to the Fusion
    placement. Add its provenance entry so the placement tes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
2026-10-16 feat(cad): place every part with a full pose; model handed parts
    Fusion is retired; the build123d model is now the master. Every part is
    placed with place(part, pos, rot): the Fusion v148 occurrence transform,
    solved for each of the 82 part instances (vertex or per-solid fits;
    most land within 1e-4 mm of Fusion). place_at() matched only the center
    of mass and hid 180-degree turns.
    Fixes found by the full poses:
    - landing gear tilt is 21.000 deg (was 21.18 from two rounded distances)
    - BL propeller turned 180 deg about its shaft (7.8 mm vertex error)
    - BC PCB (unchanged V1.3 STEP) moved down 19.2 mm into the 2312 mount
    - small offsets: CCW beams 0.024 mm, bottom interface 0.09 mm
    Handed par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
2026-10-16 docs: use BOM/CAD part numbers in the Manufacturing Guide
    The guide used Fusion instance numbers (1331-1334, 3211, 3341...), several
    of which differ from the BOM. Fusion is retired; BOM/CAD numbers win.
    - handed parts listed by hand: 1212/1213, 1221/1222, 1331/1332, 1341/1342
    - battery walls are 100x30x2 mm; busbars are 4010, 18x49x40.3 mm bent
    - CAD links point to one model per part
    - src/pcb/README: BOM numbers (main 3310, BC 3320, FC 3330, attach 3331),
    and a note that the CAD BC PCB carries parts a plain KiCad export lacks
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2026-10-16 docs(bom): confirm 1332/1342 handed pairs; note GN 237 hinge is symmetric
    Thomas confirmed the mirrored landing-gear parts are genuinely handed, so the two design TBCs on the main adapter (1332) and tube joint (1342) are resolved; the remaining note is procurement only. The enclosure hinge (JW Winco GN 237) is a symmetric COTS part, so one part number bought twice is correct and the mirrored CAD instance is just the far-side orientation.
2026-10-19 docs: remove dead Pixhawk log links from PT1 flight test reports
    flight-test/PT1/001-003.md linked DataFlash logs
    (./assets/NNN/logs/*.BIN) that were never committed to main, so the
    links 404 for readers and the Markdown Broken Link Checker has failed
    on every PR. The log numbers are kept as plain text since they map
    each flight leg to its specific log.
    Verified with the same docker image CI uses
    (ghcr.io/tcort/markdown-link-check:3.10): exit 0, was 8 dead links.
2026-10-19 docs(bom): correct the 2420 hinge note (chiral, but one part fits both sides)
    The GN 237 is chiral (alternating knuckles, bores countersunk on one face), so f2318d6 was wrong to call it symmetric. Its mounting pattern is symmetric: a stock hinge turned 180 degrees lands on the mirrored left hinge's four bores and pin line exactly, and differs only in which leaf carries which knuckle. One part number for both sides stays correct.
2026-10-19 fix(cad): one adapter, tube joint, battery wall and CCW beam part, turned not mirrored
    Thomas, Oct 19: the landing gear main adapter (one RJX part), the tube joint and the battery wall are each the same part everywhere. The CCW front beam (Fusion component 1213) is the same part as 1212 too. Fusion v148 draws one of each as a mirror image, and the Oct 16 commit split them into handed pairs; that was wrong. Back to main's single parts and STEP files: 1212 x2, 1221 x2, 1330 x4, 1340 x4.
    Placed with the same signed pose (adapter, joint) or main's turned pose (wall, front beam), each part lines up with every bore and hole of Fusion's mirror image (21/21, 38/38, 154/154 within 0.05 mm and 0.05 d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
2026-10-30 docs: review fixes, AUW arithmetic, weight table, OA open item
    Addresses the three review comments on #275: the long endurance AUW is
    11.40 + 9.65 = 21.05 kg, the MTOW row is back inside the configuration
    table with the BMS paragraph below it, and the LiDAR dropout open item is
    replaced by the MR82 phantom returns since the report already records the
    dropout as resolved.
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
